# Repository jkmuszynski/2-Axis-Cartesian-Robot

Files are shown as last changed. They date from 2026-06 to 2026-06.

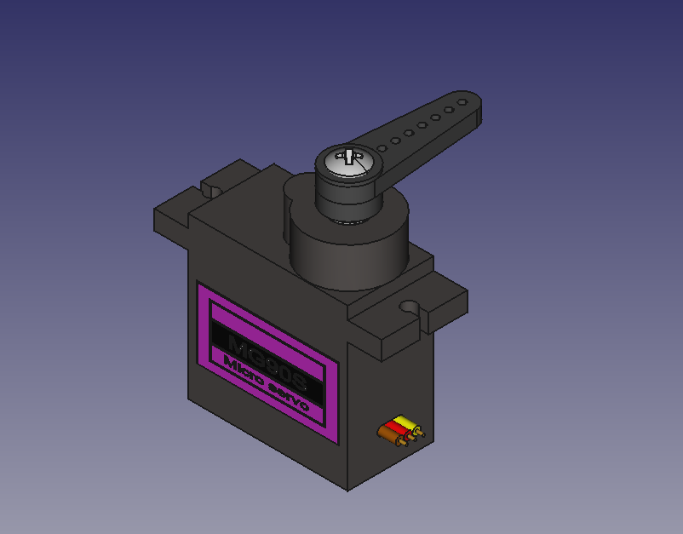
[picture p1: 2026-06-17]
Gripper/mg90_ali/mg90s_with_arm.png

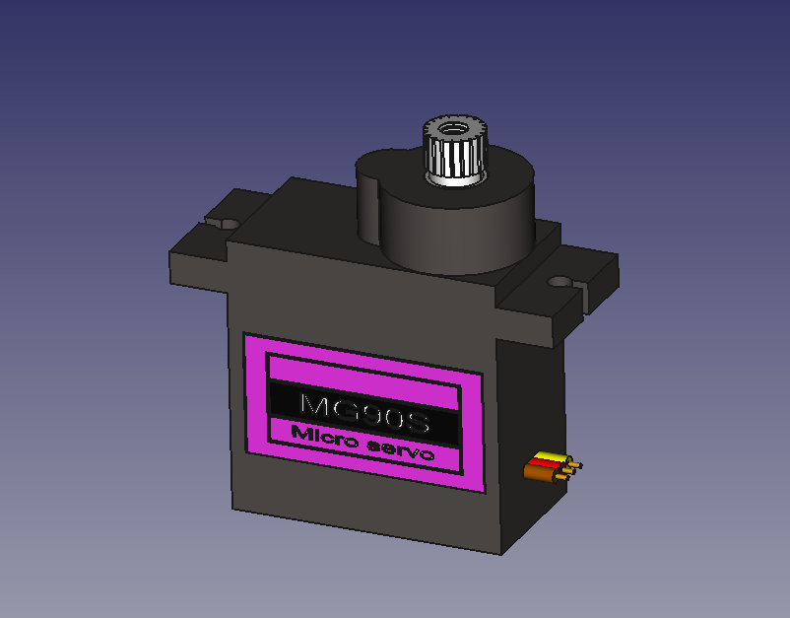
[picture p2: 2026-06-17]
Gripper/mg90_ali/mg90s.png

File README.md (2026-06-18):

# Automated Cartesian XY System

A fully functional, 2-axis Cartesian robot built with aluminum V-Slot profiles, driven by NEMA 17 stepper motors, and controlled by an STM32 microcontroller. The project features hardware-generated motion profiles, closed-loop position verification via incremental encoders, and a custom Python/PyQt6 desktop application with a real-time Digital Twin.

## 🛠️ Hardware & Mechanical Design
The physical structure was optimized for rigidity and smooth motion, utilizing standard V-Slot linear rails and custom 3D-printed parts designed in **Autodesk Fusion 360**. 
* **X-Axis:** Driven by a GT2 timing belt. The return path of the belt is smartly concealed inside the aluminum profile channel.
* **Y-Axis:** Driven by a T8 lead screw with an anti-backlash nut for high precision and self-locking capabilities.
* **Actuators & Sensors:** NEMA 17 stepper motors powered by industrial TB6600 drivers (24V). Position feedback is provided by dual-channel incremental encoders.
* **Power Management & EMI:** The system safely separates the 24V motor power supply from the 5V logic via a step-down converter. To mitigate electromagnetic interference (EMI) and ensure stable encoder readings, shielded cables were used for the motors.
* **5V-Tolerant Integration:** 5V sensors (encoders and endstops) interface directly with the 3.3V STM32 by utilizing its native 5V-tolerant (FT) hardware pins, eliminating the need for external logic level shifters.

## 💻 Embedded Firmware (STM32 / C)
The firmware is written in C using HAL libraries and is built around a robust, interrupt-driven **Finite State Machine (FSM)** ensuring non-blocking execution.
* **Hardware Motion Ramps:** A 10 kHz base timer (`TIM6`) generates smooth trapezoidal acceleration and deceleration profiles, eliminating mechanical vibrations and preventing step loss.
* **Encoder Mode:** Hardware timers (`TIM2`, `TIM3`) are configured in quadrature encoder mode for lossless step counting. A custom software delta algorithm prevents integer overflow during extended operations.
* **DMA UART Communication:** Host communication runs entirely in the background using `ReceiveToIdle_DMA`, preventing CPU stalls while parsing incoming telemetry and commands.
* **Safety & Homing:** Hardware-debounced limit switches connected to EXTI lines serve dual purposes: emergency stops (E-STOP) during standard operation, and zero-point references during the homing procedure.

## 🖥️ PC Application (Python / PyQt6)
The machine is controlled via a custom Human-Machine Interface (HMI) built with **PyQt6**.
* **Asynchronous Serial:** Communication with the STM32 is offloaded to a background `QThread` to keep the GUI fully responsive.
* **Real-Time Digital Twin:** Utilizing `pyqtgraph`, the application dynamically plots the robot's physical position in a 2D workspace based on live telemetry data from the encoders.
* **Closed-Loop Verification:** The software implements a basic closed-loop mechanism. After reaching the target, the system compares the encoder reading with the commanded position and automatically triggers a corrective movement if the error exceeds the defined tolerance.

## 🚀 Future Improvements (To Do)
While the current prototype is fully operational, several upgrades are planned:
* **Two-Stage Homing:** Improve the homing sequence by backing off the limit switch and re-approaching at a minimal speed to achieve a highly precise machine zero.
* **S-Curve Motion Profiles:** Replace the current trapezoidal ramps with S-curves to further reduce motor acoustic noise ("humming") and mechanical stress.
* **Real-Time PID Control:** Upgrade the closed-loop system from post-move verification to active, real-time error correction using a PID controller.
* **Dedicated PCB:** Design a custom printed circuit board (e.g., an STM32 shield) to replace wire-to-wire connections, integrating logic, power distribution, and opto-isolators in one module.
* **Waypoint Memory:** Implement a feature in the Python GUI to save, load, and execute complex paths consisting of multiple coordinates.

## 👨‍💻 Authors
* **Jakub Muszyński** * **Kacper Nele** *Developed as an engineering project at the Poznań University of Technology (Automatic Control and Robotics).*
efb0cb9e-aebe-48f0-bcd3-bfdc1dcb67ef

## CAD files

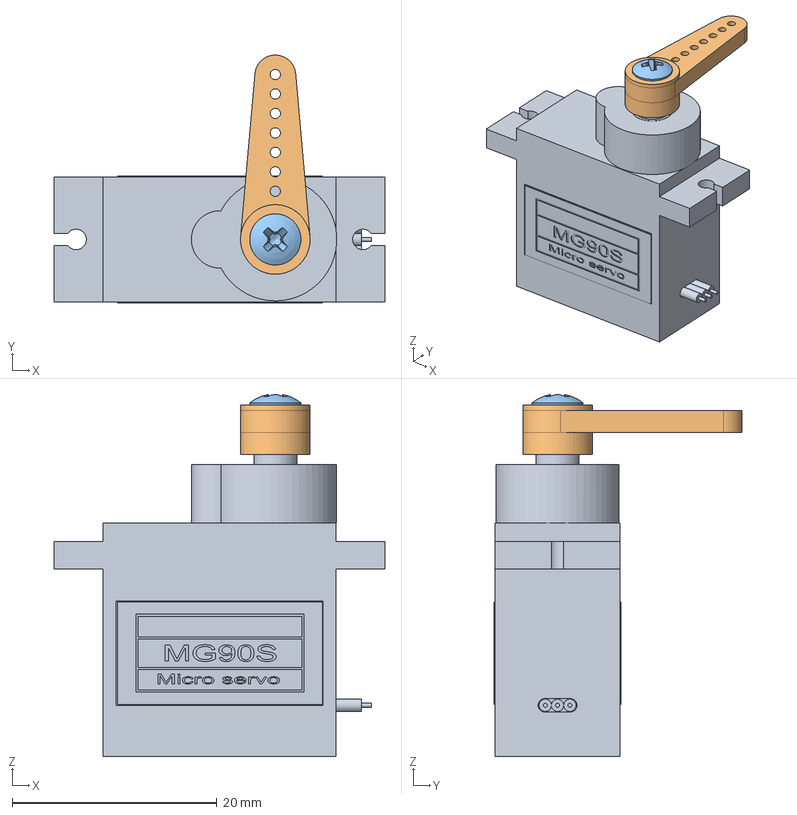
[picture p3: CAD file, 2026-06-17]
Gripper/mg90_ali/mg90s_with_arm.FCStd
32.3 x 24.2 x 35.3 mm
M90S_ali_001
MG90S_bras_01_001
M2.5x5-Screw

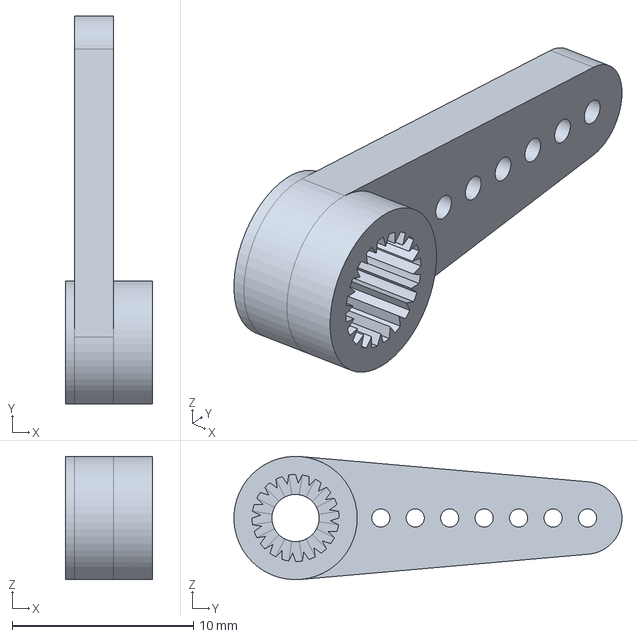
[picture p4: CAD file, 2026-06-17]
Gripper/MG90S_arm01.step
4.80 x 21.4 x 6.80 mm

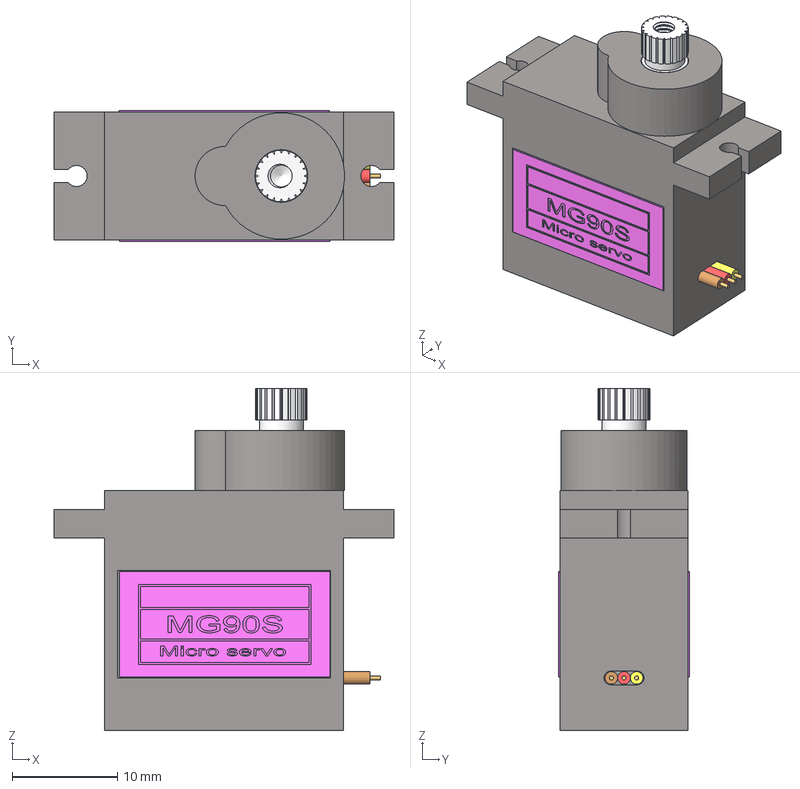
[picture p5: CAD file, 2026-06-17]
Gripper/mg90_ali/M90S_ali.FCStd
32.3 x 12.4 x 32.5 mm
axe
base001
etiquette
Tube
Cylindre
Tube001
Tube002
etiquette001
Cylindre001
Cylindre002

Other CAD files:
Gripper/mg90_ali/MG90S_bras_01.FCStd
Gripper/MG90S_arm01/MG90S_arm01/MG90S_arm01.ipt
Gripper/OldVersions/Podstawa.0008.ipt
Gripper/OldVersions/Zespół2.0007.iam
Gripper/OldVersions/adapter.0001.ipt
Gripper/OldVersions/podstawka.0002.ipt
Gripper/OldVersions/slizg.0001.ipt
Gripper/OldVersions/slizg_serwo.0001.ipt
Gripper/OldVersions/środek.0001.ipt
Gripper/Podstawa.ipt
Gripper/Zespół2.iam
Gripper/Zespół2/Design Accelerator/Przekładnia walcowa14.ipt
Gripper/Zespół2/Design Accelerator/Przekładnie walcowe4.iam
Gripper/adapter.ipt
Gripper/chwyt.ipt
Gripper/podstawka.ipt
Gripper/slizg.ipt
Gripper/slizg_serwo.ipt
Gripper/środek.ipt

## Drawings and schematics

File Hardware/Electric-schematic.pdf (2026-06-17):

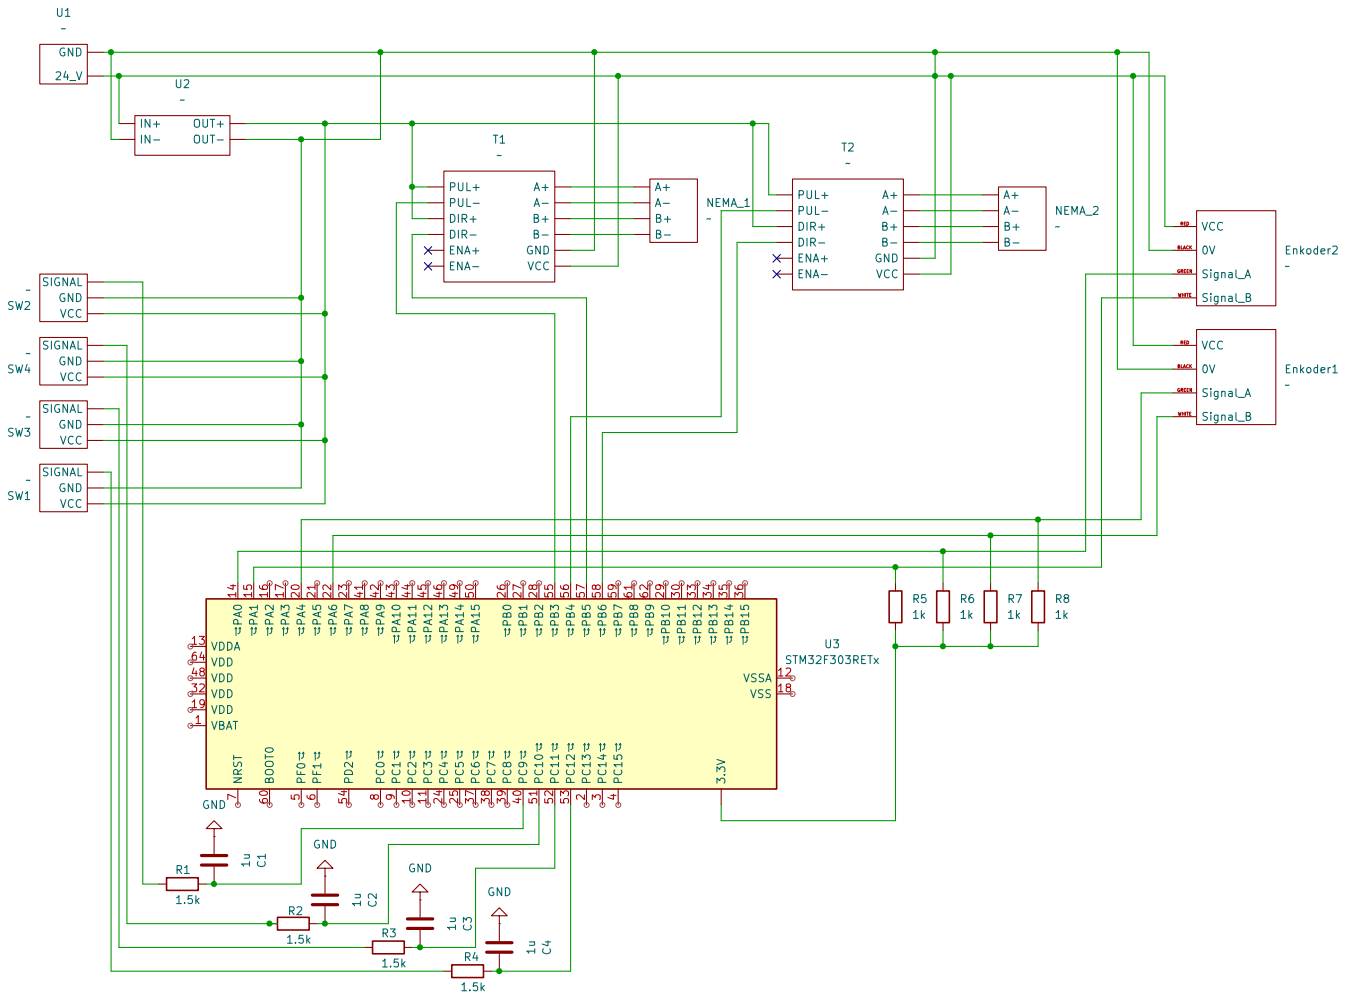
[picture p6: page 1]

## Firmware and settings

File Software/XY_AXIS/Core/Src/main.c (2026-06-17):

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
/* Includes ------------------------------------------------------------------*/
#include "main.h"

/* USER CODE BEGIN Includes */
#include <stdio.h>
#include <string.h>
#include <stdlib.h>


/* USER CODE END Includes */

TIM_HandleTypeDef htim2;
TIM_HandleTypeDef htim3;
TIM_HandleTypeDef htim6;

UART_HandleTypeDef huart2;
DMA_HandleTypeDef hdma_usart2_rx;
DMA_HandleTypeDef hdma_usart2_tx;

/* USER CODE BEGIN PV */

volatile int32_t virtual_X = 0;
volatile int32_t current_X = 0;
volatile int32_t target_X  = 0;
volatile uint8_t e_stop_flag = 0;
volatile uint32_t last_telemetry_tick = 0;
uint16_t x_last_cnt = 0;

volatile int32_t virtual_Y = 0;
volatile int32_t current_Y = 0;
volatile int32_t target_Y  = 0;
uint16_t y_last_cnt = 0;

uint8_t rx_buffer[64];
uint8_t tx_buffer[64];

typedef struct {
    volatile int32_t* current_virtual_pos;
    int32_t target_pos;
    int32_t steps_total;
    int32_t steps_done;
    int32_t accel_steps;
    uint32_t current_delay;
    uint32_t min_delay;
    uint32_t max_delay;
    uint32_t tick_counter;
    uint8_t pulse_active;
    GPIO_TypeDef* step_port;
    uint16_t step_pin;
    GPIO_TypeDef* dir_port;
    uint16_t dir_pin;
} AxisProfile_t;

volatile AxisProfile_t axisX = {&virtual_X, 0, 0, 0, 0, 30, 5, 30, 0, 0, X_STEP_GPIO_Port, X_STEP_Pin, X_DIR_GPIO_Port, X_DIR_Pin};
volatile AxisProfile_t axisY = {&virtual_Y, 0, 0, 0, 0, 30, 5, 30, 0, 0, Y_STEP_GPIO_Port, Y_STEP_Pin, Y_DIR_GPIO_Port, Y_DIR_Pin};


volatile uint8_t uart_rx_restart = 0;
volatile uint8_t cmd_ready = 0;
uint8_t cmd_buffer[64];

typedef enum {
    STATE_IDLE,
    STATE_MOVING,
    STATE_HOMING,
    STATE_VERIFYING,
	STATE_CALIBRATING
} MachineState;

volatile MachineState system_state = STATE_IDLE;
volatile uint32_t verify_timer = 0;
volatile uint8_t correction_attempts = 0;
volatile uint8_t pending_calibration_x = 0;
volatile uint8_t pending_calibration_y = 0;
volatile int32_t calibration_start_steps = 0;


volatile int32_t test_x_MAX = 0;
volatile int32_t test_x_MIN = 0;
volatile int32_t test_y_MAX = 0;
volatile int32_t test_y_MIN = 0;

/* USER CODE END PV */

void SystemClock_Config(void);
static void MX_GPIO_Init(void);
static void MX_DMA_Init(void);
static void MX_USART2_UART_Init(void);
static void MX_TIM2_Init(void);
static void MX_TIM3_Init(void);
static void MX_TIM6_Init(void);
/* USER CODE BEGIN 0 */

void ProcessAxis(volatile AxisProfile_t* axis) {
    if (axis->steps_done >= axis->steps_total) return;


    if (!axis->pulse_active && axis->tick_counter == 0) {
        if (axis->target_pos > *(axis->current_virtual_pos)) {
            HAL_GPIO_WritePin(axis->dir_port, axis->dir_pin, GPIO_PIN_RESET);
        } else {
            HAL_GPIO_WritePin(axis->dir_port, axis->dir_pin, GPIO_PIN_SET);
        }
    }
    axis->tick_counter++;

    if (!axis->pulse_active && axis->tick_counter >= axis->current_delay) {
    	axis->tick_counter = 0;

        HAL_GPIO_WritePin(axis->step_port, axis->step_pin, GPIO_PIN_RESET);
        axis->pulse_active = 1;
        axis->steps_done++;


        if (axis->target_pos > *(axis->current_virtual_pos)) {
            (*(axis->current_virtual_pos))++;
        } else {
            (*(axis->current_virtual_pos))--;
        }

        // Rampa
        int32_t steps_left = axis->steps_total - axis->steps_done;
        if (axis->steps_done < axis->accel_steps) {
            if (axis->current_delay > axis->min_delay) axis->current_delay--;
        } else if (steps_left <= axis->accel_steps) {
            if (axis->current_delay < axis->max_delay) axis->current_delay++;
        }
    }

    if (axis->pulse_active && axis->tick_counter >= 1) {
        HAL_GPIO_WritePin(axis->step_port, axis->step_pin, GPIO_PIN_SET);
        axis->pulse_active = 0;
    }
}
/* USER CODE END 0 */

/**
  * @brief  The application entry point.
  * @retval int
  */
int main(void)
{

  /* MCU Configuration--------------------------------------------------------*/

  /* Reset of all peripherals, Initializes the Flash interface and the Systick. */
  HAL_Init();

  /* Configure the system clock */
  SystemClock_Config();

  /* Initialize all configured peripherals */
  MX_GPIO_Init();
  MX_DMA_Init();
  MX_USART2_UART_Init();
  MX_TIM2_Init();
  MX_TIM3_Init();
  MX_TIM6_Init();
  /* USER CODE BEGIN 2 */
  HAL_TIM_Encoder_Start(&htim2, TIM_CHANNEL_ALL);
  HAL_TIM_Encoder_Start(&htim3, TIM_CHANNEL_ALL);
  HAL_TIM_Base_Start_IT(&htim6);

  HAL_UARTEx_ReceiveToIdle_DMA(&huart2, rx_buffer, sizeof(rx_buffer));
  __HAL_DMA_DISABLE_IT(&hdma_usart2_rx, DMA_IT_HT);

  /* USER CODE END 2 */

  /* Infinite loop */
  /* USER CODE BEGIN WHILE */
  while (1)
  {
	  if (cmd_ready) {
		  cmd_ready = 0;
		  if (cmd_buffer[0] == 'S') {
			  __disable_irq();
	          e_stop_flag = 1;
	          virtual_X = current_X; target_X = current_X;
	          virtual_Y = current_Y; target_Y = current_Y;
	          system_state = STATE_IDLE;
	          correction_attempts = 0;
	          __enable_irq();
		  }
		  else if (cmd_buffer[0] == 'M') {
			  if (e_stop_flag == 0) {
				  long parsed_X = 0, parsed_Y = 0;
				  if (sscanf((char*)cmd_buffer, "M:%ld:%ld", &parsed_X, &parsed_Y) == 2) {
					  __disable_irq();
					  target_X = parsed_X;
	                  axisX.steps_done = axisX.steps_total;
	                  axisX.target_pos = target_X;
	                  axisX.steps_total = abs(axisX.target_pos - (*axisX.current_virtual_pos));
	                  axisX.steps_done = 0;
	                  axisX.current_delay = axisX.max_delay;
	                  axisX.accel_steps = axisX.steps_total / 3;
	                  if (axisX.accel_steps > 400) axisX.accel_steps = 400;
	                  axisX.tick_counter = 0;
	                  axisX.pulse_active = 0;

	                  target_Y = parsed_Y;
	                  axisY.steps_done = axisY.steps_total;
	                  axisY.target_pos = target_Y;
	                  axisY.steps_total = abs(axisY.target_pos - (*axisY.current_virtual_pos));
	                  axisY.steps_done = 0;
	                  axisY.current_delay = axisY.max_delay;
	                  axisY.accel_steps = axisY.steps_total / 3;
	                  if (axisY.accel_steps > 400) axisY.accel_steps = 400;
	                  axisY.tick_counter = 0;
	                  axisY.pulse_active = 0;
                      system_state = STATE_MOVING;
                      correction_attempts = 0;
                      __enable_irq();
	                    }
	                }
	            }
	            else if (cmd_buffer[0] == 'H') {
	                if (e_stop_flag == 0) {
	                    __disable_irq();

	                    // Homing X
	                    target_X = -99999;
	                    axisX.steps_done = axisX.steps_total;
	                    axisX.target_pos = -99999;
	                    axisX.steps_total = 99999;
	                    axisX.steps_done = 0;
	                    axisX.current_delay = axisX.max_delay;
	                    axisX.accel_steps = 200;
	                    axisX.tick_counter = 0; axisX.pulse_active = 0;

	                    // Homing Y
	                    target_Y = -99999;
	                    axisY.steps_done = axisY.steps_total;
	                    axisY.target_pos = -99999;
	                    axisY.steps_total = 99999;
	                    axisY.steps_done = 0;
	                    axisY.current_delay = axisY.max_delay;
	                    axisY.accel_steps = 200;
	                    axisY.tick_counter = 0; axisY.pulse_active = 0;

	                    system_state = STATE_HOMING;
	                    correction_attempts = 0;
	                    __enable_irq();
	                }
	            }
	            else if (cmd_buffer[0] == 'C') {
	                if (e_stop_flag == 0) {
	                    __disable_irq();
	                    pending_calibration_x = 1;
	                    pending_calibration_y = 1;


	                    target_X = -99999; axisX.steps_done = axisX.steps_total; axisX.target_pos = -99999;
	                    axisX.steps_total = 99999; axisX.steps_done = 0; axisX.current_delay = axisX.max_delay;
	                    axisX.accel_steps = 200; axisX.tick_counter = 0; axisX.pulse_active = 0;

	                    target_Y = -99999; axisY.steps_done = axisY.steps_total; axisY.target_pos = -99999;
	                    axisY.steps_total = 99999; axisY.steps_done = 0; axisY.current_delay = axisY.max_delay;
	                    axisY.accel_steps = 200; axisY.tick_counter = 0; axisY.pulse_active = 0;

	                    system_state = STATE_HOMING;
	                    correction_attempts = 0;
	                    __enable_irq();
	                }
	            }
	            else if (cmd_buffer[0] == 'R') {
	                __disable_irq();
	                e_stop_flag = 0;
	                target_X  = current_X; virtual_X = current_X; axisX.target_pos = current_X; axisX.steps_done = axisX.steps_total;
	                target_Y  = current_Y; virtual_Y = current_Y; axisY.target_pos = current_Y; axisY.steps_done = axisY.steps_total;

	                system_state = STATE_IDLE;
	                correction_attempts = 0;
	                __enable_irq();
	            }
	        }

	        // --- MASZYNA STANÓW: ZAKOŃCZENIE RUCHU I KOREKTA ---

	        if (system_state == STATE_MOVING && axisX.steps_done >= axisX.steps_total && axisY.steps_done >= axisY.steps_total) {
	            system_state = STATE_VERIFYING;
	            verify_timer = HAL_GetTick();
	        }

	        if (system_state == STATE_VERIFYING && (HAL_GetTick() - verify_timer > 100)) {


	            int32_t expected_encoder_x = (target_X * 16249) / 21798;
	            int32_t error_x = expected_encoder_x - current_X;


	            int32_t expected_encoder_y = (target_Y * 50608) / 8452;
	            int32_t error_y = expected_encoder_y - current_Y;

	            if (abs(error_x) > 5 || abs(error_y) > 5) {
	                if (correction_attempts < 3) {
	                    correction_attempts++;
	                    __disable_irq();


	                    if (abs(error_x) > 5) {
	                        int32_t steps_to_correct_x = (error_x * 21798) / 16249;
	                        target_X = target_X + steps_to_correct_x;
	                        axisX.target_pos = target_X;
	                        axisX.steps_total = abs(steps_to_correct_x);
	                        axisX.steps_done = 0;
	                        axisX.current_delay = axisX.max_delay;
	                        axisX.accel_steps = axisX.steps_total / 2;
	                        axisX.tick_counter = 0; axisX.pulse_active = 0;
	                    }


//	                    if (abs(error_y) > 5) {
//	                        int32_t steps_to_correct_y = error_y;
//	                        target_Y = target_Y + steps_to_correct_y;
//	                        axisY.target_pos = target_Y;
//	                        axisY.steps_total = abs(steps_to_correct_y);
//	                        axisY.steps_done = 0;
//	                        axisY.current_delay = axisY.max_delay;
//	                        axisY.accel_steps = axisY.steps_total / 2;
//	                        axisY.tick_counter = 0; axisY.pulse_active = 0;
//	                    }

	                    system_state = STATE_MOVING;
	                    __enable_irq();
	                } else {
	                    system_state = STATE_IDLE;
	                    if (huart2.gState == HAL_UART_STATE_READY) {
	                        sprintf((char*)tx_buffer, "ERR:Limit korekt przekroczony\n");
	                        HAL_UART_Transmit_DMA(&huart2, tx_buffer, strlen((char*)tx_buffer));
	                    }
	                }
	            } else {
	                system_state = STATE_IDLE;
	                correction_attempts = 0;
	                if (huart2.gState == HAL_UART_STATE_READY) {
	                    sprintf((char*)tx_buffer, "OK:%ld:%ld\n", current_X, current_Y);
	                    HAL_UART_Transmit_DMA(&huart2, tx_buffer, strlen((char*)tx_buffer));
	                }
	            }
	        }


	        if (HAL_GetTick() - last_telemetry_tick >= 50) {
	            last_telemetry_tick = HAL_GetTick();


	            uint16_t raw_x = (uint16_t)TIM2->CNT;
	            current_X += (int16_t)(raw_x - x_last_cnt);
	            x_last_cnt = raw_x;

	            uint16_t raw_y = (uint16_t)TIM3->CNT;
	            current_Y += (int16_t)(raw_y - y_last_cnt);
	            y_last_cnt = raw_y;


	            if (huart2.gState == HAL_UART_STATE_READY) {
	                sprintf((char*)tx_buffer, "P:%ld:%ld\n", current_X, current_Y);
	                HAL_UART_Transmit_DMA(&huart2, tx_buffer, strlen((char*)tx_buffer));
	            }
	        }


    /* USER CODE END WHILE */

    /* USER CODE BEGIN 3 */
  }
  /* USER CODE END 3 */
}

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
/* USER CODE BEGIN 4 */


void HAL_UARTEx_RxEventCallback(UART_HandleTypeDef *huart, uint16_t Size)
{
    if (huart->Instance == USART2) {
        HAL_GPIO_TogglePin(LD2_GPIO_Port, LD2_Pin);

        if (Size > 0 && Size < sizeof(rx_buffer)) {
            rx_buffer[Size] = '\0';
            memcpy(cmd_buffer, rx_buffer, Size + 1);
            cmd_ready = 1;
        }


        memset(rx_buffer, 0, sizeof(rx_buffer));
        HAL_UART_DMAStop(&huart2);
        HAL_UARTEx_ReceiveToIdle_DMA(&huart2, rx_buffer, sizeof(rx_buffer));
        __HAL_DMA_DISABLE_IT(&hdma_usart2_rx, DMA_IT_HT);
    }
}


void HAL_TIM_PeriodElapsedCallback(TIM_HandleTypeDef *htim)
{
    if (htim->Instance == TIM6) {
        if (e_stop_flag) return;
        ProcessAxis(&axisX);
        ProcessAxis(&axisY);
    }
}


void HAL_GPIO_EXTI_Callback(uint16_t GPIO_Pin)
{

    // --- LEWA KRAŃCÓWKA (MIN) X ---
    if (GPIO_Pin == X_MIN_Pin) {
    	test_x_MIN++;
        if (system_state == STATE_CALIBRATING) return;

        TIM2->CNT = 0; current_X = 0; virtual_X = 0; target_X = 0;
        axisX.target_pos = 0; axisX.steps_done = axisX.steps_total; x_last_cnt = 0;


        e_stop_flag = 0;

        if (pending_calibration_x == 1) {
            pending_calibration_x = 0;
            target_X = 99999; axisX.target_pos = 99999; axisX.steps_total = 99999; axisX.steps_done = 0;
            axisX.current_delay = axisX.max_delay; axisX.accel_steps = 200; axisX.tick_counter = 0; axisX.pulse_active = 0;
            system_state = STATE_CALIBRATING;
        } else {

            if (axisY.steps_done >= axisY.steps_total) system_state = STATE_IDLE;
        }
    }
    // --- PRAWA KRAŃCÓWKA (MAX) X LUB PRZYCISK ---
    else if (GPIO_Pin == X_MAX_Pin || GPIO_Pin == B1_Pin) {
    	test_x_MAX++;
        axisX.steps_done = axisX.steps_total;

        if (system_state == STATE_CALIBRATING && GPIO_Pin == X_MAX_Pin) {
            int32_t motor_steps_taken = virtual_X;
            if (huart2.gState == HAL_UART_STATE_READY) {
                sprintf((char*)tx_buffer, "CAL_X:%ld:%ld\n", motor_steps_taken, current_X);
                HAL_UART_Transmit_DMA(&huart2, tx_buffer, strlen((char*)tx_buffer));
            }
            if (axisY.steps_done >= axisY.steps_total) system_state = STATE_IDLE;
        } else {
            e_stop_flag = 1; target_X = current_X; virtual_X = current_X;
            system_state = STATE_IDLE; correction_attempts = 0;
        }
    }



    // --- LEWA KRAŃCÓWKA (MIN) Y ---
    else if (GPIO_Pin == Y_MIN_Pin) {
    	test_y_MIN++;
        if (system_state == STATE_CALIBRATING) return;

        TIM3->CNT = 0; current_Y = 0; virtual_Y = 0; target_Y = 0;
        axisY.target_pos = 0; axisY.steps_done = axisY.steps_total; y_last_cnt = 0;
        e_stop_flag = 0;

        if (pending_calibration_y == 1) {
            pending_calibration_y = 0;
            target_Y = 99999; axisY.target_pos = 99999; axisY.steps_total = 99999; axisY.steps_done = 0;
            axisY.current_delay = axisY.max_delay; axisY.accel_steps = 200; axisY.tick_counter = 0; axisY.pulse_active = 0;
            system_state = STATE_CALIBRATING;
        } else {
            if (axisX.steps_done >= axisX.steps_total) system_state = STATE_IDLE;
        }
    }
    // --- PRAWA KRAŃCÓWKA (MAX) Y ---
    else if (GPIO_Pin == Y_MAX_Pin) {
    	test_y_MAX++;
        axisY.steps_done = axisY.steps_total;

        if (system_state == STATE_CALIBRATING) {
            int32_t motor_steps_taken = virtual_Y;
            if (huart2.gState == HAL_UART_STATE_READY) {
                sprintf((char*)tx_buffer, "CAL_Y:%ld:%ld\n", motor_steps_taken, current_Y);
                HAL_UART_Transmit_DMA(&huart2, tx_buffer, strlen((char*)tx_buffer));
            }
            if (axisX.steps_done >= axisX.steps_total) system_state = STATE_IDLE;
        } else {
            e_stop_flag = 1; target_Y = current_Y; virtual_Y = current_Y;
            system_state = STATE_IDLE; correction_attempts = 0;
        }
    }
}

/* USER CODE END 4 */
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


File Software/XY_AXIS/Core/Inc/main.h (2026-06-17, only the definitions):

#define B1_Pin GPIO_PIN_13
#define B1_GPIO_Port GPIOC
#define B1_EXTI_IRQn EXTI15_10_IRQn
#define USART_TX_Pin GPIO_PIN_2
#define USART_TX_GPIO_Port GPIOA
#define USART_RX_Pin GPIO_PIN_3
#define USART_RX_GPIO_Port GPIOA
#define LD2_Pin GPIO_PIN_5
#define LD2_GPIO_Port GPIOA
#define X_MAX_Pin GPIO_PIN_9
#define X_MAX_GPIO_Port GPIOC
#define X_MAX_EXTI_IRQn EXTI9_5_IRQn
#define TMS_Pin GPIO_PIN_13
#define TMS_GPIO_Port GPIOA
#define TCK_Pin GPIO_PIN_14
#define TCK_GPIO_Port GPIOA
#define X_MIN_Pin GPIO_PIN_10
#define X_MIN_GPIO_Port GPIOC
#define X_MIN_EXTI_IRQn EXTI15_10_IRQn
#define Y_MIN_Pin GPIO_PIN_11
#define Y_MIN_GPIO_Port GPIOC
#define Y_MIN_EXTI_IRQn EXTI15_10_IRQn
#define Y_MAX_Pin GPIO_PIN_12
#define Y_MAX_GPIO_Port GPIOC
#define Y_MAX_EXTI_IRQn EXTI15_10_IRQn
#define X_STEP_Pin GPIO_PIN_3
#define X_STEP_GPIO_Port GPIOB
#define Y_STEP_Pin GPIO_PIN_4
#define Y_STEP_GPIO_Port GPIOB
#define X_DIR_Pin GPIO_PIN_5
#define X_DIR_GPIO_Port GPIOB
#define Y_DIR_Pin GPIO_PIN_6
#define Y_DIR_GPIO_Port GPIOB

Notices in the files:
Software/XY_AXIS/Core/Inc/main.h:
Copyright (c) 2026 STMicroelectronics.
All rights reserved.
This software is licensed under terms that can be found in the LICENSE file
